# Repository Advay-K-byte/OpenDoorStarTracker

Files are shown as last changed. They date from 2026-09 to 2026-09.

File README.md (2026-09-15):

# OpenDoorStarTracker
An extremely budget friendly barn-door based star tracker, based on ESP32 and 28BYJ stepper motor.

This project is aimed to reduce the cost of entry level astrophotography, by providing a simple, highly open source and customizable barn-door star tracker base design.

Features:
  - ~$30 total cost
  - ESP32 webpage controller with easy slewing adjustment, resetting and tracking speed adjustments
  - Powered 100% with a USB battery

OnShape full cad model: https://cad.onshape.com/documents/74c63627717610043aa96174/w/ea7d6111b83551bf0402bd96/e/efb1aef8f325fa2de03cf594 

BOM: https://docs.google.com/spreadsheets/d/1jzOKhSsxTXtr95Q2sw8j4dyO4oUSdCoERQhsF2ek0W0/edit?usp=sharing

YOUTUBE VIDEO: https://youtu.be/rEIXzPVLKTk?si=SgSztPYLGnnmBQIM

DIY Telescope (1)
fullTracker


Camera Mount Printables link: https://www.printables.com/model/81126-tripod-ball-head
Thank you zx82net, @zx82net_107245 on Printables!
# Motion:
The OpenDoor Star Tracker uses a barn-door tracker design with a ¼ inch (20TPI) screw and nut rotating at 1 rpm to move at the sidereal rate.
- MOTOR: 28-BYJ Stepper motor
- SCREW: 1/4" x 20Teeth per Inch Screw hand curved
- GEARS: 5:1 3d printed gear with pushed in nut

# Electronics:
- DRIVER: ULN2003 Driver
- CONTROLLER: ESP32 board with wifi
- POWER: Any USB Battery Bank
- ATTACHMENT: You can solder the driver to the ESP32 to be more compact using a perfboard, like I did, or use normal Arduino jumper wires
- Lots of opportunity for expansion

# WiFi Controller Software:
  - Speed adjustment (automatically saves to esp32 preferences so you dont have to change it every time)
  - Position adjustment (always live updating position value as the tracking moves)
  - Slewing
  - Automatic zero reset
  - Manual zero position setting
ControllerProgram

I also controlled my camera wirelessly through the Camera Control software made for olympus cameras. If you want your rig to be fully 100% automated, I highly reccomend to use a wire, or wireless setup connected to a laptop running a program, or get an intervalometer.
It feels way more advanced if you do not have to touch anything, and it likely improved image quality, as you are not touching the easily moveable or sensitive ball head.

# Polar Alignment:
  - SCOPE: I recommend to use a cheap toy refractor, and lock the focus at infinity. Can be bought from classified or any old small refractor.
  - ALTERNATIVES: You can simply aim polaris using just the line of the hinge, or add a straw or circle hooks
  - Can be adjusted using the EQ Wedge for alt, and the main base for az.

# Camera Mount:
The Camera Ball Head is fully 3d printed. Thank you to user zx82net, @zx82net_107245 on Printables! I modified the base to make it an easier angle at my latitude to point the camera anywhere.
I mounted this, on the side of the mount that is higher up, to offset the weight of the rest of the tripod so the eq wedge has less force on it, and also to allow for better southern aiming, and general zenith aiming.

# EQ Wedge:
The EQ wedge is fully 3d printed, other than a few hinge screws. my size is for 1/4" but you can adjust in cad using step source cad.
I added some sandpaper inbetween for additional camera safety, but it should work without it.

I managed to get a really good deal on this Bushnell NorthStar 114/900 scope and tripod for 10 USD on Facebook Marketplace. I would highly recommend finding some better tripod than a photography tripod, as this setup can weigh a lot more than just a DSLR camera.
NorthStar

# Results:
This is my very first acceptable Milky Way shot:
  - Cygnus Region
  - ~35min exposure
  - 30 second exposures
  - Olympus OMD EM10 at 14mm kit lens at f/4.5
  - Bortle 6 light pollution

I will get much better photos soon, when I have time.

# Prototyping:
I went through many different versions, originally starting with a arduino mega, as it was all I had, and using a barely mounted straight screw. It was very bad, and I only got up to 10 second exposures. In this design, there was no polar scope, only a cheap photography tripod for adjustment. The second version slowly got better, adding a scope, and improving the code with the arduino. The final V3, uses and ESp32 and curved screw for best tracking while very little additional cost.
workingPrototype

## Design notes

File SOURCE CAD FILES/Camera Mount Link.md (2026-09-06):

The camera mount is a model from Printables.com. Link is here: https://www.printables.com/model/81126-tripod-ball-head 

Thank you to user zx82net, @zx82net_107245 on printables for this file.

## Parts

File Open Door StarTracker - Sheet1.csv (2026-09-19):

OpenDoor Star Tracker
GITHUB: https://github.com/Advay-K-byte/OpenDoorStarTracker/tree/main |  | OnShape CAD: https://cad.onshape.com/documents/74c63627717610043aa96174/w/ea7d6111b83551bf0402bd96/e/efb1aef8f325fa2de03cf594
ITEM | DESC | PRICE (1) | QUANITITY | SUBTOTAL | LINK
STRUCTURAL:
Wood Base Pieces | About 1cmx14cmx33cm plywood |  |  |  |  |  | Any cheap small plywood board works.
Door Hinge | standard door hinge | 3 |  |  | Home Depot | Amazon
Door hinge Screw Support | small block of wood to support door hinge screws |  |  |  |  |  | this was specifically for me, but can be edited for different kinds of tripod mounts
EQ Wedge tracker mount | 3d printed. Mounts to the tracker bottom
EQ wedge base mount | 3d printed. Mounts to tripod base w/ 4" screw |  | 1
EQ wedge star tracker screws | All 1/4" 20tpi. base: 4" tracker: 1" hinge: 2" | 4 |  |  | Home Depot |  | Any general screw works. Please edit the CAD model to fit whatever size you have locally.
Nuts | All 1/4" 20tpi. 5x normal nuts. 2x wingnuts | 2
MOTION:
Curved Screw | 1/4" 20tpi x 3ft. Mounted w/ 2x normal nuts | 3 | 1 |  | Home Depot | Amazon | Much better to buy locally rather than shipped. 1/4" 20TPI is preffered, but you can probably change rotation speed
50T gear + 10T gear | 3d printed. 50T gear w/ normal nut. |  | 2
Camera Mount | 3d printed. link: printables
ELECTRONICS:
28BYJ-48 Stepper Motor | Mounted w/ repurposed screws | 3 |  |  | Micro Center | Amazon | I recommend to buy in a large pack with included matching drivers for cheap and easy to use system.
28BYJ -48 Motor Driver | ULN 2003A driver. very simple to use | comes w/ motor |  |  | Micro Center | Amazon
ESP32 | only $16 for 3. only $6 per board. | 6 |  |  | Micro Center | Amazon
Power Wire | General ESP32 data wire (USBC or Micro USB)
USB Power Bank | Any size normal USB power bank made for phone
(optional) Perfboard | Use if you can solder, or just use arduino jumpers |  |  |  |  | Amazon
Jumper wires | Use this or/with a breadboard for standard. | 5 |  |  |  | Amazon
Electronics Bay | 3d Printed. Mounted w/ reused screws
 | TOTAL: | 26

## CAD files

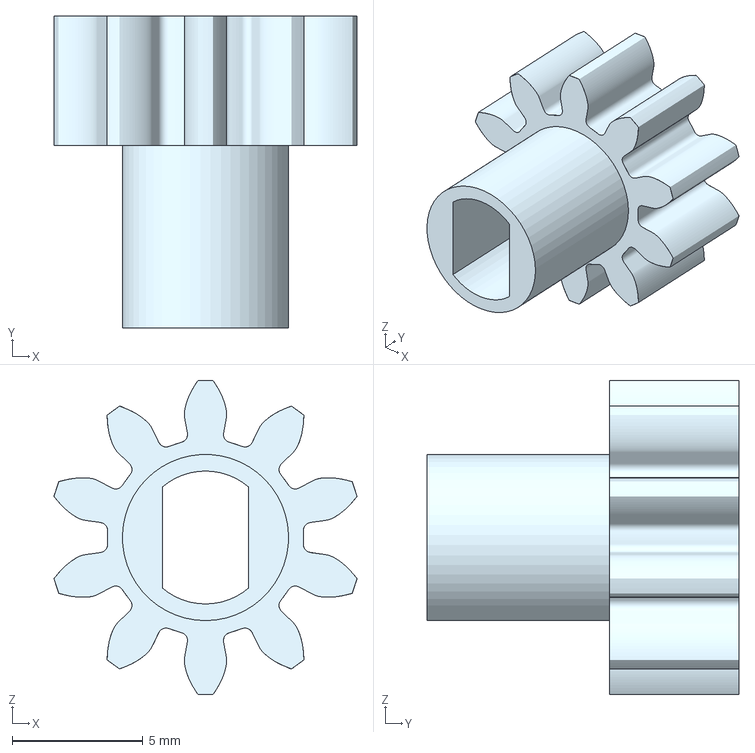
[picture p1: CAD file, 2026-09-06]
SOURCE CAD FILES/10t gear.step
11.6 x 11.9 x 12.0 mm

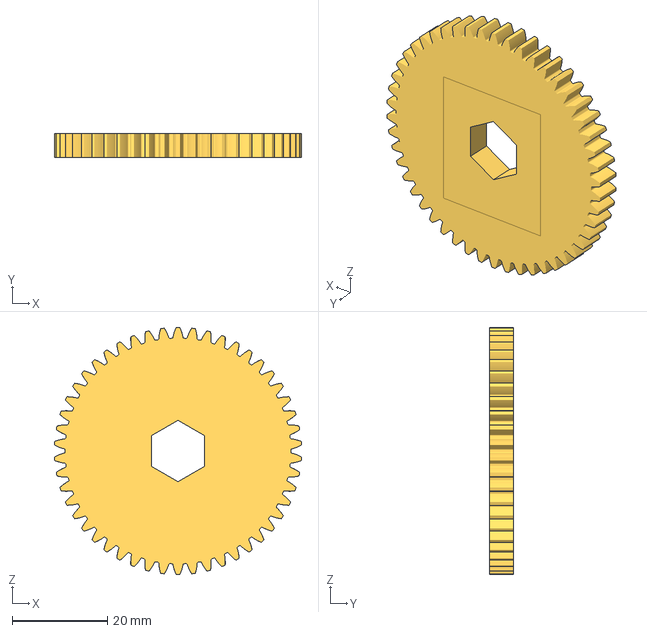
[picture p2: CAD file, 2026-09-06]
SOURCE CAD FILES/50T gear.step
51.9 x 5.00 x 52.0 mm

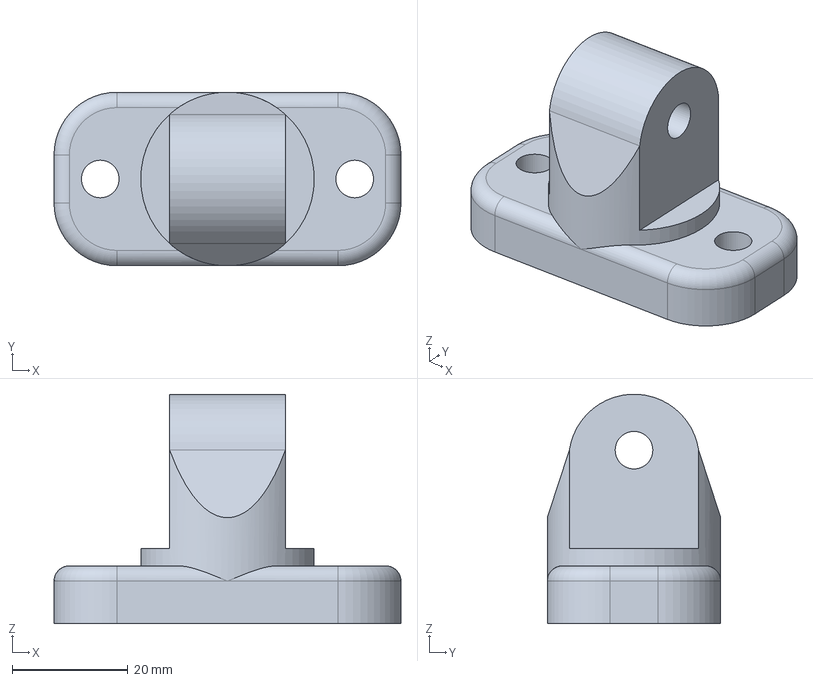
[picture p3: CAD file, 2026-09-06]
SOURCE CAD FILES/EQ Wedge Tracker Mount.step
60.0 x 30.0 x 39.6 mm

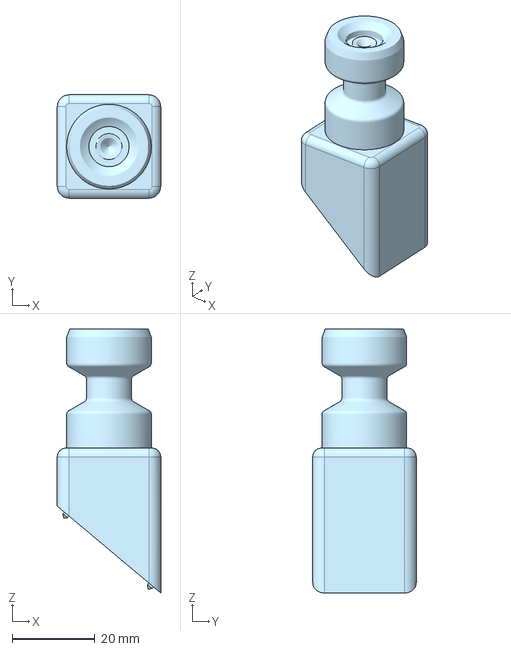
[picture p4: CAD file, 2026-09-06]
SOURCE CAD FILES/Camera Wedge +Post.step
25.0 x 25.0 x 63.8 mm

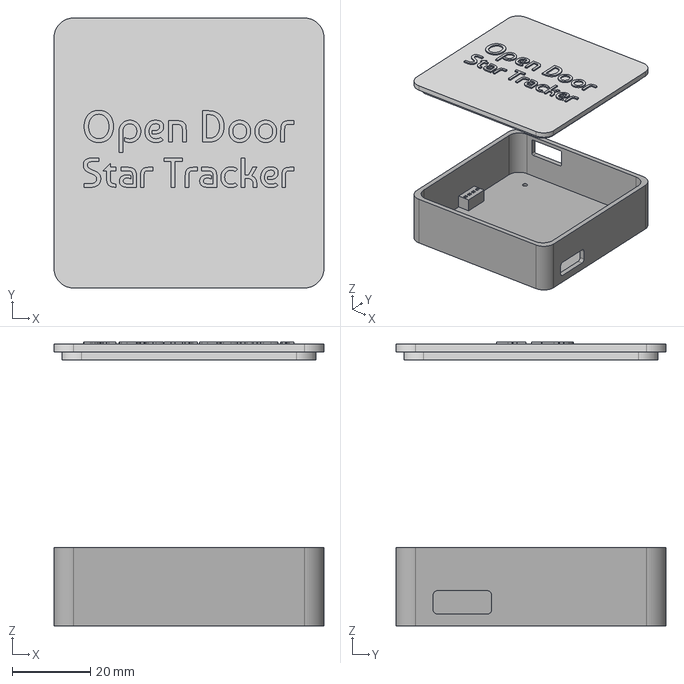
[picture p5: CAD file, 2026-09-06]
SOURCE CAD FILES/ElectronicsBay.step
69.0 x 69.0 x 72.5 mm

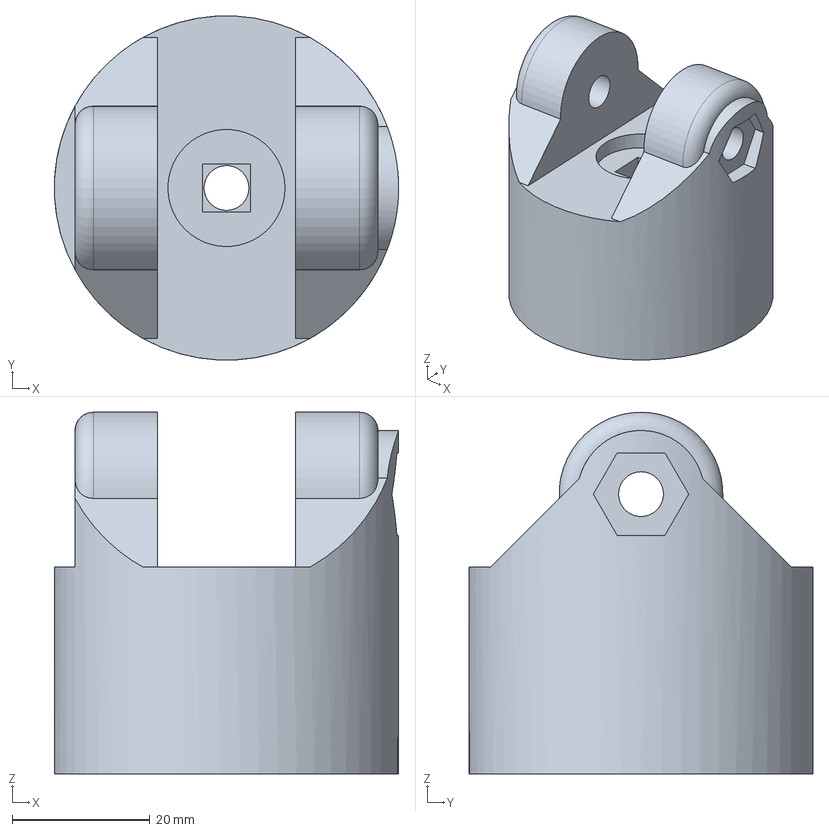
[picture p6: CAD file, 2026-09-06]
SOURCE CAD FILES/EQ Wedge Base.step
50.0 x 50.0 x 52.5 mm

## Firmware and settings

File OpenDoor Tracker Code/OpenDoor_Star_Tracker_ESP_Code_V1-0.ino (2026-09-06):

//OpenDoor Star Tracker CODE
//GITHUB: https://github.com/Advay-K-byte/OpenDoorStarTracker/tree/main
//This is a very open source and highly changeable project, you can change many things to fit whatever resources you have available.
// Good luck, and clear skies!


#include <Preferences.h>
#include <WiFi.h>
#include <WebServer.h>

Preferences prefs;  //makes preferences object

// set Access Point network name and password
const char* AP_SSID = "OpenDoor Star Tracker";
const char* AP_PASSWORD = "MoreThanAstrophotography";

//starts webserver at port 80 of wifi
WebServer server(80);

const int IN1 = 33;
const int IN2 = 25;
const int IN3 = 26;
const int IN4 = 32;

const int stepSequence[4][4] = {
  {1, 1, 0, 0},
  {0, 1, 1, 0},
  {0, 0, 1, 1},
  {1, 0, 0, 1}
};

int stepIndex = 0;


const int stepsPerRevolution = 2038;


float pos = 0;
const double mmPerStep = 0.000124632;
const int stepsPermm = 8024;

bool trackingState = false;
bool resetState = false;
bool slewState = false;

int slewDir = -1;
int slewmm = 5;
float targetPos = 0;

float trackingSpeed = 5.9;    //set the speed for now in rpm
unsigned long lastStepTime = 0;    // the last time it took a step
unsigned long stepIntervalMicros = 5400;                                     //speed setting basically
unsigned long stepIntervalResetMicros = 1500; //speed setting of the resetting speedbasically
unsigned long stepIntervalSlewing = 1500; //sets slewing speed

                 //full html page that is sent over the wifi connection to the client
const char* htmlPage = R"rawliteral(
  <!DOCTYPE HTML>
  <html>
      
  <head><title>OpenDoor Star Tracker Controller</title></head>
  <style>
      body {
          background-color:#f25c5c;
          text-align:center;
      }
      h1 {
          /*header size one css */
          text-align:center;
          font-family: Andale Mono, monospace;
      }
      h2 {
          /*header size two css */
          text-align:center;
          font-family: Andale Mono, monospace;
      }
      h3 {
          /*header size three css */
          text-align:center;
          font-family: Andale Mono, monospace;
      }
      h4 {
          /*header size four css */
          text-align:center;
          font-family: Andale Mono, monospace;
      }
      h5 {
          /*header size five css */
          text-align:center;
          font-family: Andale Mono, monospace;
      }
      button {
          /*header size button css */
          text-align:center;
          font-family: Andale Mono, monospace;
          border-radius: 20px;
      }
      
      
  </style>
  <body>
    <h1>OpenDoor Star Tracker Controller</h1>
    <hr style="width:70%;"> <!--divider horizontal rule-->
    <h2>TRACKING:</h2>                                                      <!--TRACKING ONOFF-->
    <button style="padding:25px; color:red ; background-color:black; font-weight:bold;font-size:60px;" id="tracking">OFF</button>
    
    
    <h3>Current Tracking Speed</h3>
    <div style="display: flex; gap:50px; justify-content: center;">           <!--TRACKING SPEED-->
        <button style="padding:25px;" onclick="addSpeed()">+10</button>
        <h1 id="trackingSpeed">0</h1>
        <button style="padding:25px;" onclick="minusSpeed()">-10</button>
    </div>
    
    <hr style="width:30%;">
    
    <h3>Slew Position</h3>
    <div style="display: flex; gap:30px; justify-content: center;">           <!--SLEW POSITION-->
        <button style="padding:25px;" onclick="slewOne()">+1mm</button>
        <button style="padding:25px;" onclick="slewFive()">+5mm</button>
        <h1 id="motorPos">0</h1>
        <button style="padding:25px;" onclick="slewMinusFive()">-5mm</button>
        <button style="padding:25px;" onclick="slewMinusOne()">-1mm</button>
    </div>
    
    <hr style="width:30%;">
    
    <h3>Settings controls:</h3>                                                <!--SETTINGS CONTROLS-->
    <div style="display: flex; gap:20px; justify-content: center;">
        <button style="padding:15px;" onclick="nightMode()">NIGHT MODE</button>
        <button style="padding:15px;" onclick="resetPosition()">RESET TRACKER</button>
        <button style="padding:15px;" onclick="setZeroPos()">SET POSITION 0</button>
    </div>
    </div>
    
    
    
    <script>                                                              <!-- JAVASCRIPT CODE STARTS HERE -->
      
      
      const trackbutton = document.getElementById("tracking");    //tracking button code to change color + send fetch
                                                                  //this is for elements that have to be changed, hence ID
      const posLabel = document.getElementById("motorPos");
      
      const speedLabel = document.getElementById("trackingSpeed");
      
      
      
                      //SINGLE PRESS BUTTONS FUNCTIONS
      function addSpeed(){
          fetch('/addSpeed')
              .then(response => response.text())
              .then(newSpeed =>{
              speedLabel.textContent = newSpeed;   
              });
      }
      function minusSpeed(){
          fetch('/minusSpeed')
              .then(response => response.text())
              .then(newSpeed =>{
              speedLabel.textContent = newSpeed;   
              });
      }
      function slewFive() {
          if (trackbutton.textContent == "OFF"){
              fetch('/slewFive');
          }

      }
      function slewMinusFive() {
          if (trackbutton.textContent == "OFF"){
              fetch('/slewMinusFive');
          }
      }
      function slewOne() {
          if (trackbutton.textContent == "OFF"){
              fetch('/slewOne');
          }
      }
      function slewMinusOne() {
          if (trackbutton.textContent == "OFF"){
              fetch('/slewMinusOne');
          }
      }
      function updatePosition(){
          fetch("/getPosition")
              .then(response => response.text()) //get a simple text back
              .then(data => {
                  posLabel.textContent = data;
              })
              .catch(error => console.error("ERROR FETCHING POSITION:", error ));
          
      }
      
      function setZeroPos(){
          fetch("/setZeroPos");
      }
      function resetPosition(){
          if (trackbutton.textContent == "OFF"){
              fetch("/resetPosition");
          }
          
      }
      setInterval(updatePosition, 200);
      
                        //MAINTRACKING OFF/ON RELOADING
                        
      window.addEventListener("DOMContentLoaded", function(){    //does this right when the tab is loaded up
          fetch("/getTrackingState")             //sends fetch command
              .then(response =>{                 //then the esp does the fetch command, and send reply
                if (response.ok){              // if that reply is ok, then we are good no error
                    return response.text();
                } 
                throw new Error("Response was not OK");
                  
              })
              .then(data =>{                   // now we see if the data is equal to tracking has been turned on
                  if (data === "stateOn"){
                      trackbutton.textContent = "ON";           //change colors
                      trackbutton.style.backgroundColor = "#ffffff";
                      trackbutton.style.color = "#000000";
                  }
                  else if (data === "stateOff"){
                          trackbutton.textContent = "OFF";
                          trackbutton.style.backgroundColor = "#000000";
                          trackbutton.style.color = "#ff0000";
                      }
                  else{
                      trackbutton.textContent = "ERROR";
                  }
              })
          fetch("/getSpeed")
              .then(response => response.text())
              .then(data => {
                  speedLabel.textContent = data;
              });
          }); //ends window.eventlistner
          
          
          
          
                    //IF THE TRACKBUTTON IS PRESSED
                    
      trackbutton.addEventListener('click', function(){
          if (trackbutton.textContent == "OFF"){     //if the text in the button is OFF,
              fetch('/trackingOn')                   // send the fetch command
                  .then(response =>{                 //then the esp does the fetch command, and send reply
                    if (response.ok){              // if that reply is ok, then we are good no error
                        return response.text();
                    } 
                    throw new Error("Response was not OK");
                      
                  })
                  .then(data =>{                   // now we see if the data is equal to tracking has been turned on
                      if (data === "trackingHasBeenTurnedOn"){
                          trackbutton.textContent = "ON";           //change colors
                          trackbutton.style.backgroundColor = "#ffffff";
                          trackbutton.style.color = "#000000";
                      }
                      else{
                          trackbutton.textContent = "ERROR";         //sends error if the function in esp does not spin motor
                      }
                  })
          }
          else if (trackbutton.textContent == "ON"){  //same code to turn off
              fetch('/trackingOff')
                  .then(response =>{
                    if (response.ok){
                        return response.text();
                    } 
                    throw new Error("Response was not OK");
                      
                  })
                  .then(data =>{
                      if (data === "trackingHasBeenTurnedOff"){
                          trackbutton.textContent = "OFF";
                          trackbutton.style.backgroundColor = "#000000";
                          trackbutton.style.color = "#ff0000";
                      }
                      else{
                          trackbutton.textContent = "ERROR";
                      }
                  })
          }
      });
      
      
      
      
    </script>
  </body>
  </html>
)rawliteral";

void stepMotorDirect(int direction){
  if (direction > 0){
    stepIndex = (stepIndex + 1) % 4;
  } else {
    stepIndex = (stepIndex - 1 + 4) % 4;
  }
  digitalWrite(IN1, stepSequence[stepIndex][0]);
  digitalWrite(IN2, stepSequence[stepIndex][1]);
  digitalWrite(IN3, stepSequence[stepIndex][2]);
  digitalWrite(IN4, stepSequence[stepIndex][3]);
}
//functions that the esp32 does after webpage sends fetch command

void handleRoot(){
  server.send(200,"text/html", htmlPage);           //Handleroot is the main command when the webpage is opened, 
                                                    // it sends the whole webpage through http, displaying the html port 200
}

void trackingOn(){
  Serial.println("Tracking Turned On...");
  trackingState = true;
  server.send(200, "text/plain","trackingHasBeenTurnedOn");
}

void trackingOff(){
  Serial.println("Tracking Turned Off...");
  trackingState = false;
  digitalWrite(IN1, LOW);
  digitalWrite(IN2, LOW);
  digitalWrite(IN3, LOW);
  digitalWrite(IN4, LOW);
  server.send(200, "text/plain","trackingHasBeenTurnedOff");
}

void getTrackingState(){
  Serial.println(trackingState);
  if (trackingState){
    server.send(200,"text/plain","stateOn");
  }
  else {
    server.send(200,"text/plain","stateOff");
  }
}

int slewspeed = 2;   //Sets slewing speed from 2 is fast, 8 is slow

void slewFive(){
  Serial.print("Slewing +5mm");
  slewState = true;
  slewDir = -1;
  slewmm = 5;
  targetPos = pos + slewmm;
  server.send(200, "text/plain","OK");
}

void slewMinusFive(){

  Serial.print("Slewing -5mm");
  slewState = true;
  slewDir = 1;
  slewmm = 5;
  targetPos = pos - slewmm;
  server.send(200, "text/plain","OK");


}

void slewOne(){

  Serial.print("Slewing +1mm");
  slewState = true;
  slewDir = -1;
  slewmm = 1;
  targetPos = pos + slewmm;
  server.send(200, "text/plain","OK");

}

void slewMinusOne(){

  Serial.print("Slewing -1mm");
  slewState = true;
  slewDir = 1;
  slewmm = 1;
  targetPos = pos - slewmm;
  server.send(200, "text/plain","OK");

}

void getPosition(){
  server.send(200, "text/plain", String(pos) );
}

void setZeroPos(){
  pos = 0;
}

void resetPosition(){
  if (pos > 0){
    float stepsToMove = pos * stepsPermm;
    Serial.print("Resetting started");
    resetState = true;


  }
}

void slewStep(int dir, int mm){
  unsigned long currentMicros = micros(); //micros() is the onboard clock in microseconds

  if (dir == -1){

    //targetPos = pos + mm;

    if (pos < targetPos){
      if (currentMicros - lastStepTime >= stepIntervalSlewing){
        lastStepTime = currentMicros;                              
        stepMotorDirect(-1);
        Serial.print(".");

        pos = pos + mmPerStep;
      }
    }
    if (pos >= targetPos){
      Serial.println(" ");
      Serial.println("FINISHED SLEWING");
      slewState = false;
      digitalWrite(IN1, LOW);
      digitalWrite(IN2, LOW);
      digitalWrite(IN3, LOW);
      digitalWrite(IN4, LOW);
    }
  }

  else if (dir == 1){
    //targetPos = pos - mm;

    if (pos > targetPos){
      if (currentMicros - lastStepTime >= stepIntervalSlewing){
        lastStepTime = currentMicros;                              
        stepMotorDirect(1);
        Serial.print(".");

        pos = pos - mmPerStep;
      }
    }
    if (pos <= targetPos){
      Serial.println(" ");
      Serial.println("FINISHED SLEWING");
      slewState = false;
      digitalWrite(IN1, LOW);
      digitalWrite(IN2, LOW);
      digitalWrite(IN3, LOW);
      digitalWrite(IN4, LOW);
    } 
  }
}

void addSpeed(){
  stepIntervalMicros += 10;

  prefs.begin("tracker",false);
  prefs.putULong("speed", stepIntervalMicros);
  prefs.end();
  
  server.send(200, "text/plain", String(stepIntervalMicros));
}

void minusSpeed(){
  stepIntervalMicros -= 10;

  prefs.begin("tracker",false);
  prefs.putULong("speed", stepIntervalMicros);
  prefs.end();
  
  server.send(200, "text/plain", String(stepIntervalMicros));
}

void getSpeed(){
  server.send(200, "text/plain", String(stepIntervalMicros));
}


void setup() {


  pinMode(IN1, OUTPUT);
  pinMode(IN2, OUTPUT);
  pinMode(IN3, OUTPUT);
  pinMode(IN4, OUTPUT);

  Serial.begin(115200);

  prefs.begin("tracker", false);
  //prefs.clear();
  stepIntervalMicros = prefs.getULong("speed", 5400);  //read the stores speed or default to 5400
  prefs.end(); // ends prefereences handle


  //starts access point
  WiFi.softAP(AP_SSID, AP_PASSWORD);
  Serial.println("Access point started");
  Serial.print("IP Adress: ");
  Serial.println(WiFi.softAPIP()); // normally 192.168.4.1

  server.on("/", handleRoot);
  server.on("/trackingOn",trackingOn);
  server.on("/trackingOff",trackingOff);
  server.on("/getTrackingState",getTrackingState);
  server.on("/slewFive",slewFive);
  server.on("/slewMinusFive", slewMinusFive);
  server.on("/slewOne",slewOne);
  server.on("/slewMinusOne", slewMinusOne);
  server.on("/getPosition", getPosition);
  server.on("/setZeroPos", setZeroPos);
  server.on("/resetPosition", resetPosition);
  server.on("/addSpeed", addSpeed);
  server.on("/minusSpeed", minusSpeed);
  server.on("/getSpeed", getSpeed);

  server.begin();

  Serial.print("Interval: ");
  Serial.println(stepIntervalMicros);
}

void loop() {

  server.handleClient();

  if (trackingState && !resetState && !slewState){
    unsigned long currentMicros = micros(); //micros() is the onboard clock in microseconds
  
    if (currentMicros - lastStepTime >= stepIntervalMicros){
      lastStepTime = currentMicros;                              // if the current micro second on the clock time - the last time a step was taken,
                                                                 // is greater than the number of time per step, then take set the last time a step
                                                                 // was taken to current time, and step by 1
      stepMotorDirect(-1);

      pos = pos + mmPerStep;
    }
  }
  if (resetState && !trackingState && !slewState ){
    unsigned long currentMicros = micros(); //micros() is the onboard clock in microseconds
    
    if (pos > 0){
      
      if (currentMicros - lastStepTime >= stepIntervalResetMicros){
      lastStepTime = currentMicros;                              // if the current micro second on the clock time - the last time a step was taken,
                                                                 // is greater than the number of time per step, then take set the last time a step
                                                                 // was taken to current time, and step by 1
      stepMotorDirect(1);
      Serial.print(".");

      pos = pos - mmPerStep;
      }
    }
    if (pos <= 0){
      Serial.println(" ");
      Serial.println("FINISHED RESETTING");
      resetState = false;
      digitalWrite(IN1, LOW);
      digitalWrite(IN2, LOW);
      digitalWrite(IN3, LOW);
      digitalWrite(IN4, LOW);
    }
    
  }
  if (slewState && !trackingState && !resetState){
    slewStep(slewDir, slewmm);
  }

}

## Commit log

2026-08-28 Update README with CAD model and BOM links
    Added links to OnShape CAD model and BOM.
2026-09-06 Add files via upload
    Source Files for 3d printed parts.
    [Camera Wedge +Post.step, EQ Wedge Base.step, EQ Wedge Tracker Mount.step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]
2026-09-06 Add .gitignore for Arduino IDE and system files
2026-09-06 Added ElectronicsBay.step
    [ElectronicsBay.step]
2026-09-06 Add camera mount model link and user credit
    Added a link to the camera mount model from Printables.com and credited the user who provided the file.
2026-09-06 Update README with Camera Mount Printables link
    Added Camera Mount Printables link and acknowledgment.
2026-09-15 Enhance README with video link and motor details
    Added video link and updated motor specifications.
2026-09-15 Update README with camera mount printables link
    Added camera mount printables link and attribution.
2026-09-15 Update README with electronics and setup details
    Added details about electronics, software, polar alignment, camera mount, and results.
2026-09-15 Fix formatting and update camera mount information
2026-09-15 Enhance README with camera control and setup tips
    Added recommendations for wireless camera control and adjustments for camera mount and EQ wedge.
2026-09-19 BOM CSV file
    [Open Door StarTracker - Sheet1.csv]
